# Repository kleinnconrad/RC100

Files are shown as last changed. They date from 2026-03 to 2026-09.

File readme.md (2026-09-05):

# 1:10 onroad RC car for speeds over 100 km/h

This project covers the system architecture and configuration of an 1:10 scale on-road touring car with the design goal of a consistently repeatable top speed of over 100 km/h without risking the car to be damaged or destroyed. The focus is on maximizing drive power while ensuring reliability and cost efficiency.

The technical challenge primarily results from the chosen scale and the limited tire diameter of 64 millimeters. While vehicles from 1:8 scale have physical advantages due to higher mass inertia, larger rolling circumferences, and a longer wheelbase, the 1:10 scale requires significantly higher rotor speeds. This leads to high mechanical stresses in the drivetrain. The low vehicle weight also requires precise aerodynamic and suspension tuning to ensure driving stability at high speeds.

The artefacts of this repository are:
* Architecture decision records (ADRs) in the `/architecture` directory
* System specification in the `specs/full_spec.yml` file
* Vehicle setup configurations in the `/setup_sheets` directory

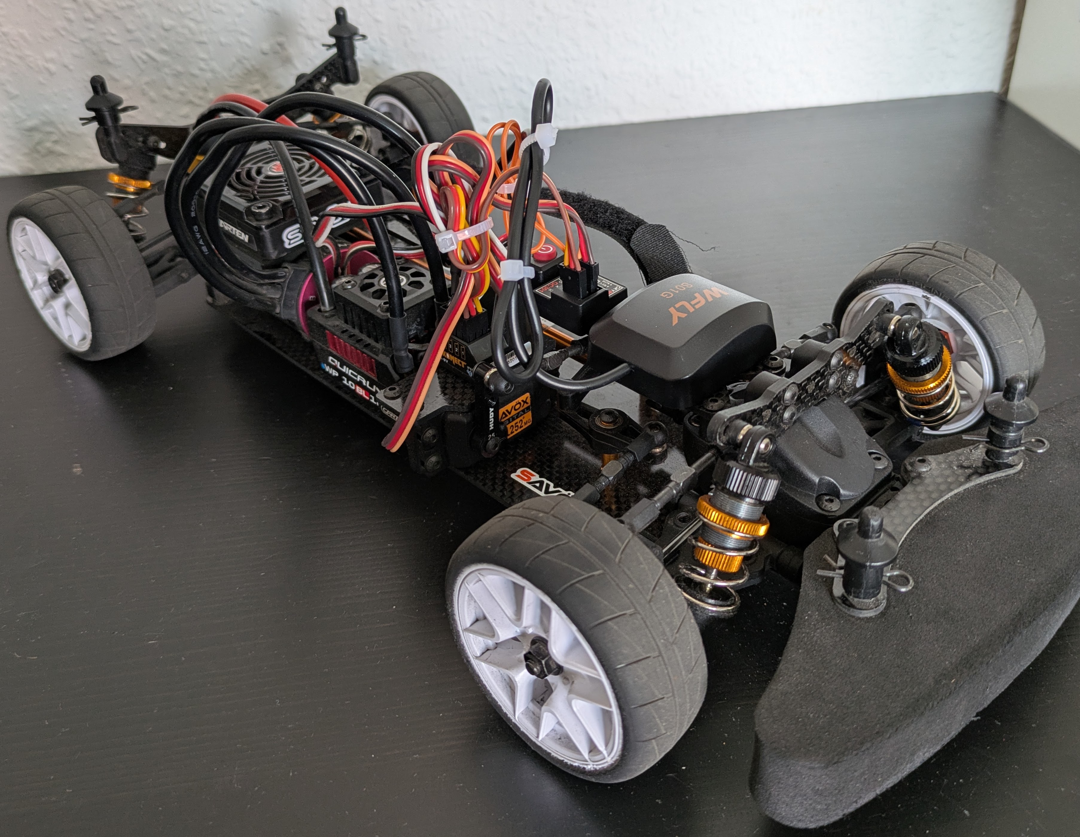
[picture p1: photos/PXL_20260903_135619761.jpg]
RC Car Photo 1
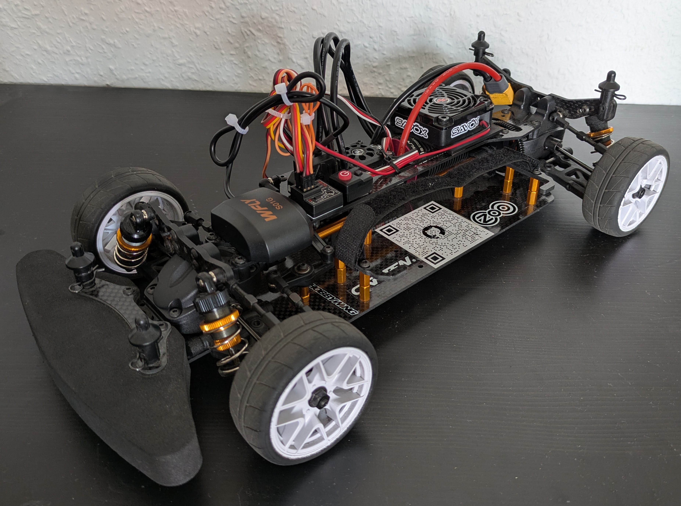
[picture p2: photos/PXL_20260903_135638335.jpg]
RC Car Photo 2
 

## Table of contents
* [Repository structure](#repository-structure)
* [Artefacts (ADR, specs, setup sheets)](#artefacts-adr-specs-setup-sheets)
* [Calculation models for drivetrain design](#calculation-models-for-drivetrain-design)
* [Learnings & modifications](#learnings--modifications)
* [Repository automation](#repository-automation)
* [Follow-up project: Telemetry system](#follow-up-project-telemetry-system)
* [Licensing](#licensing)

## Repository structure
* **`/architecture`**: Documentation of basic system designs
* **`/docs`**: Static web dashboard for visualizing the latest setup configurations
* **`/photos`**: Central directory for all image files
* **`/project`**: General project information
  * **`/costs`**: Cost tracking
  * **`/follow_up_projects`**: Documentation of related follow-up projects
* **`/scripts`**: Automation scripts
  * **`/calc`**: Calculation scripts
  * **`/plots`**: Generated plots
* **`/setup_sheets`**: Vehicle setup configurations
* **`/specs`**: Specifications of the vehicle components
  * **`/electronics`**: Selection and specification of electronic components such as motors, electronic speed controllers, and batteries
  * **`/mechanics`**: Chassis design, construction data, and specification of physical components
* **`/testing`**: Test results and performance measurement data
  * **`/error_list`**: Error logs and their resolutions
  * **`/tests`**: Logs and data of test drives

## Artefacts (ADR, specs, setup sheets)
The documentation of architecture decisions (ADRs), the specifications of all mechanical and electronic components, and the vehicle setup configurations are consistently maintained as structured YAML files (`.yml` or `.yaml`). The formal hierarchical structure of these artefacts is standardized as follows:

```mermaid
classDiagram
    class adr {
        +id: String
        +title: String
        +status: String
        +date: Date
        +context: Text
        +decision: String
        +rationale: Text
        +consequences: List
    }
    class adr_alternative {
        +option_id: Integer
        +name: String
        +type: String
        +evaluation: Text
    }
    adr *-- adr_alternative : considered_alternatives
    
    class spec {
        +properties: Object
        +integration_notes: Object
    }
    class spec_meta {
        +brand: String
        +model: String
        +type: String
    }
    spec *-- spec_meta : meta

    class setup {
    }
    class setup_meta {
        +date: Date
        +description: String
        +version: String
        +top_speed_kmh: Float
    }
    class setup_properties {
        +suspension_and_geometry: Object
        +drivetrain: Object
        +electronics_and_control: Object
    }
    setup *-- setup_meta : meta
    setup *-- setup_properties : properties
```

## Calculation models for drivetrain design
To avoid thermal or mechanical overload of the electronic components, custom-developed calculation models are used:
* **Gearing calculator (`scripts/calc/getriebe_calc.py`)**: Simulates the mechanical wheel load for the motor based on tire diameter and target speed, depending on available motor pinions. Setups are categorized into load zones for the defined drive system.
* **Limit calculator (`scripts/calc/max_speed.py`)**: Calculates the achievable top speed considering specific motor data, battery voltage, and defined thermal tolerance limits based on physical hardware specifications.

## Learnings & modifications (so far...)
This section documents the findings from previous tests & speedruns in 1:10 scale as well as the resulting modifications to the vehicle.

| Driving operation & environment |
|:---|
| **[L] Track selection**<br>A suitable track is crucial for success. Clean asphalt is absolutely necessary. The track should preferably not be bordered by walls or curbs. A minimum width of 8 meters is required. |
| **[L] Weather**<br>The weather is also important. Ensure there is no wind and conditions are dry. |
| **[L] Safety**<br>If the conditions are not right and you don't have a good feeling, no speedrun should be undertaken. |
| **[L] Driving practice**<br>You must learn to drive. It is necessary to familiarize yourself with the vehicle and the acceleration curve. It is important to steer the vehicle smoothly when it is far away. |

| Suspension & geometry |
|:---|
| **[M] Dampers & springs**<br>Very viscous shock oil was used and spring preload maximized. Stiff suspension is absolutely necessary to prevent loss of control due to diving. |
| **[M] Suspension geometry**<br>Rear toe-in of 2.5 degrees and 0 degrees camber. Front 0 degrees toe-in and 0 degrees camber. No experiments should be made here. |
| **[M] Sway bars**<br>The sway bars were removed. They are unnecessary for speedruns and pose a potential source of error. |
| **[M] Droop screws**<br>The droop screws were removed. Since the track is not manually cleaned, further lowering is not constructive. The screws are unnecessary for the regular 1:10 speedrun. |
| **[L] Weight distribution**<br>Care must be taken to ensure an even left/right weight distribution. Furthermore, the front must not be too light. |

| Drivetrain |
|:---|
| **[L] Motorization**<br>Sufficient motorization is less of a problem than often assumed. You shouldn't invest too much here. |
| **[M] Motor & gearing**<br>Use of a 3660 motor with a tall gear ratio instead of the usual 3650 motor. The motorization must be adapted to the available track. |
| **[M] Differential (front)**<br>A front spool was installed. During straight-line running at maximum speed, diff-out must be absolutely avoided; speed compensation is not desired. |
| **[L] Differential (rear)**<br>Making the rear differential stiffer is not necessary. The front spool is sufficient. |
| **[L] Thermal management**<br>Problems with ESC and motor temperature have not occurred yet. The problem is apparently overrated. |

| Electronics & control |
|:---|
| **[L] Control components**<br>**Do not skimp on the remote control and servo**. Lack of precision makes steering corrections a game of chance. You must invest in a remote control with hall sensors and a decent digital servo. |
| **[L] Assistance systems**<br>**Using a Gyro really makes a difference** and is highly recommended. |
| **[L] Steering mechanics**<br>The steering mechanism must move without resistance when disconnected from the servo. Mechanical resistance prevents the servo from returning precisely to the neutral position during slow steering inputs. In this state, the servo stops visibly but continues to draw current, indicated by audible noise, as it attempts to reach the neutral position. |
| **[L] `Steering Exponential Curve` (cubic polynomial)**<br>The steering exponential curve requires precise configuration. A setting of approximately -30 is recommended. |
| **[L] `Throttle Exponential Curve` (cubic polynomial)**<br>The throttle exponential curve requires precise configuration. A setting of approximately -40 is recommended. |

| Chassis & assembly |
|:---|
| **[L] Material selection**<br>Not all plastic parts should be replaced with aluminum. You must consider which parts are allowed to be destroyed in a crash. If easily replaceable plastic parts are replaced with aluminum, the impact energy finds more unfavorable paths. |
| **[L] Threadlocker**<br>Loctite on metal connections is absolutely mandatory. |
| **[L] Body**<br>The body should not be painted. A clear body allows a necessary view of the technology at all times. |
| **[L] Aerodynamics**<br>A wedge shape of the vehicle is necessary for efficient aerodynamics. To achieve this, the front body posts must be shortened as much as possible. |
| **[M] C-hub assembly**<br>The mounting screws of the C-hubs were loosened to eliminate mechanical resistance. Excessive tightening prevents the steering from moving freely, resulting in the previously described issue of an inaccurate servo neutral return. |
| **[M] Servo saver**<br>The servo saver was removed and an aluminum servo horn was mounted directly. This increases the risk of damage to the servo in the event of a crash. The servo saver was identified as a source of failure (steering oscillation) during speedruns. |

*(Legend: **[L]** = learning, **[M]** = modification)*

## Repository automation
Maintaining the specifications and architecture decisions formatted as YAML files triggers automated processes:
* **Aggregation of specifications**: Individual hardware specifications are merged into a central specification file in the root directory.
* **Cost overview**: Bill of materials and shopping lists are automatically derived from the specifications and updated.
* **Decision log**: Architecture decisions are automatically compiled into a chronological log.

## Follow-up project: Telemetry system
This project is followed by an independent project concerned with the development of a telemetry data system based on an ESP32 microcontroller. The goal is the sensory recording and transmission of driving dynamics parameters of the RC vehicle.



## Licensing
* The source code of the calculation models is subject to the MIT license.
* The hardware design, documentation, specifications, and test results are released under the Creative Commons attribution 4.0 international license. Own adaptations and commercial use are permitted, provided authorship is acknowledged.

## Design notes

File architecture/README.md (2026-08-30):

# Architecture Decision Records (ADRs)

This directory contains all fundamental architecture and hardware decisions for the RC100 project. **This file is generated automatically. Please do not edit manually.**

## Overview

| ID | Date | Title | Status | Decision |
| :--- | :--- | :--- | :--- | :--- |
| **ADR-001** | 2026-03-06 | Selection of the chassis platform and make-or-buy decision (100 km/h Benchmark) | 🟢 decided | MAKE - Carten T410R |
| **ADR-002** | 2026-03-06 | Selection of the brushless motor combo for 100 km/h speedruns | 🟢 decided | Hobbywing QuicRun WP10BL120 G2 Combo (3660SL 3700KV) |
| **ADR-003** | 2026-03-06 | Selection of the LiPo Battery for the 100 km/h Goal. | 🟢 decided | Absima GreenHorn Line V2 (3S / 5000mAh / 50C / Hardcase) |
| **ADR-004** | 2026-03-06 | Selection of the charger for 3S LiPo batteries | 🟢 decided | SkyRC S100neo |
| **ADR-005** | 2026-08-20 | Selection of the remote control system for 100 km/h speedruns | 🟢 decided | X9S Radio + Mini Waterproof 4-Channel Receiver RG4CHWP |
| **ADR-006** | 2026-08-21 | Selection of the steering servo for precise high-speed control | 🟢 decided | Savöx SC-1252MG+ |
| **ADR-007** | 2026-03-06 | Selection of active and passive motor cooling for 3S speedruns | 🟢 decided | Passive 36mm Alu Heat Sink combined with active 40x40mm High-Speed Alu Fan |
| **ADR-008** | 2026-02-25 | Selection of tires (belted rubber tires for asphalt) for 100 km/h speedruns | 🟢 Decided | Sweep HANKOOK Tread Belted tires Pre-glued set Pro-compound 36deg for Asphalt (SR-SSF-36AWPG) |
| **ADR-009** | 2026-03-12 | Selection of the aerodynamic body for 100 km/h speedruns | 🟢 decided | ZooRacing Hellcat (190 mm, 0.7mm thickness) |
| **ADR-010** | 2026-03-10 | Selection of the GPS measuring system to validate the 100 km/h mark | 🟢 decided | Ruddog GPS Performance Analyzer |
| **ADR-011** | 2026-08-30 | Selection of Gyro for vehicle stabilization | 🟢 Decided | SkyRC GC301 Gyro |

---

## Detailed Logs

### ADR-001: Selection of the chassis platform and make-or-buy decision (100 km/h Benchmark)
**Status:** decided | **Date:** 2026-03-06

#### Context
For the 100 km/h speedrun project, a mechanically stable basis is required. 
The platform must withstand 
extreme loads (approx. 44,000 rpm at the motor, massive 
centrifugal forces on the axles). 
The fundamental architecture question (Make or Buy) compares the construction of an own budget kit ("Make") 

with the purchase of an expensive, pre-assembled high-end competition chassis ("Buy"
). 
A critical risk for 3S use are differential gears made of plastic/composite, 
which often cannot withstand the torque.

#### Decision
> **MAKE - Carten T410R**

#### Rationale
The decision is made in favor of the "Make" option with the Carten T410R 
(~ 180 €). 
It is the only kit in the benchmark field of this price class that 
combines the essential requirements 
for a 3S/100 km/h run out of the box: 
1. A stiff 3mm carbon bottom plate (prevents dangerous fluttering). 
2. A robust shaft drive (eliminates the risk of skipping belts). 
3. Differential gears made of sintered metal (solves the knockout criterion of shearing 
plastic diffs). 
The massive price advantage over the Xray X4 '24 fully justifies 
the increased manual setup effort.

#### Consequences
- The metal differentials of the T410R must be shimmed precisely to guarantee zero play.
- The central aluminum driveshaft must be checked for concentricity before installation, as strong vibrations can occur with shaft setups.

---

### ADR-002: Selection of the brushless motor combo for 100 km/h speedruns
**Status:** decided | **Date:** 2026-03-06

#### Context
In order to accelerate a 1/10 touring car (Carten T410R) to 100 km/h, 
the gearing must be very 'tall' (high wheel load > 22 %). A 
classic 3650 motor (50 mm length) operates 
here at its thermal 
load limit. A drivetrain is absolutely required 
that delivers enough mechanical torque (motor size 3660) at 3S voltage 
(11.1V) and 
whose electronic speed controller (ESC) can safely handle the high stall currents during acceleration 
(min. 120A).

#### Decision
> **Hobbywing QuicRun WP10BL120 G2 Combo (3660SL 3700KV)**

#### Rationale
The decision is made in favor of the Hobbywing QuicRun G2 Combo. It eliminates 
the risk of failure of 
no-name motors and offers an optimally coordinated architecture (firmware of ESC 
and motor timing are optimally interlocked). 
The 3660 motor delivers the perfect 
rpm with its 3700KV on 3S 
(approx. 41,000 rpm) and has enough torque due to the longer rotor 
to confidently handle 
the calculated wheel load of approx. 24 %. This is the safest and 
most efficient solution on a budget under 100 €.

#### Consequences
- Packaging (Installation space): The 3660 motor is 10 mm longer than the standard size. The ESC and the receiver must be placed correspondingly further back in the T410R chassis.
- Pinion bore (IMPORTANT): Hobbywing usually delivers the 3660SL G2 with a 5.0 mm shaft (verify specifications with the dealer finally before ordering the pinion). A 48dp pinion with a 5 mm bore (e.g. Robinson Racing) is absolutely required.
- Power supply: The system voltage is strictly limited to 3S LiPo. A 4S operation would exceed the maximum permissible rotor speed of the motor.

---

### ADR-003: Selection of the LiPo Battery for the 100 km/h Goal.
**Status:** decided | **Date:** 2026-03-06

#### Context
In order to accelerate the RC100 project to over 100 km/h, the power source must be optimally 
matched to the 4000kV motor and the 120A ESC (Hobbywing QuicRun). 
A 2S LiPo (7.4V) would only deliver approx. 29,600 rpm, which is not sufficient for 100 km/h 
with a normal gear ratio. Therefore, a 3S LiPo (11.1V) is absolutely necessary to 
reach the calculated ~44,400 rpm. In addition, the battery must be able to briefly 
deliver extreme currents without dropping in voltage (voltage sag), and must be physically 
protected in the event of a crash at high speed.

#### Decision
> **Absima GreenHorn Line V2 (3S / 5000mAh / 50C / Hardcase)**

#### Rationale
The decision is made in favor of the Absima GreenHorn V2 3S LiPo. With a 50C 
discharge rate, it offers 
enough buffer for the massive current peaks when accelerating 
the 64T/38T gearing. 
The hardcase is a safety requirement for speedruns, as an impact at 100 km/h 
would immediately destroy and ignite a softcase LiPo. The pre-assembled XT60 connector 
guarantees a 
low contact resistance for the high currents.

#### Consequences
- Chassis modification: Since 3S hardcase batteries are approx. 35mm high, the upper carbon battery brace in the Carten T410R must be raised with 10mm spacers and longer M3 screws.
- Connector compatibility: The Hobbywing controller must absolutely be soldered with a matching XT60 connector (no Tamiya connectors at these currents!).
- Safety: Charging and storing the battery (55.5 Wh) may only be done under supervision in a Bat-Safe or a fireproof LiPo bag.

---

### ADR-004: Selection of the charger for 3S LiPo batteries
**Status:** decided | **Date:** 2026-03-06

#### Context
Charging the 3S LiPo battery defined in ADR-003 (11.1V, 5000mAh, 55.5 
Wh) requires a 
safe and powerful charger. To gently charge the battery 
with 1C (5 Amps), 
a charging power of at least 63 Watts 
(5 Amps * 12.6V end-of-charge voltage) is required. 
In addition, the charger must 
exactly monitor the cell voltages (balancing) and be able to measure the internal 
resistance of the cells to prevent fire hazards. The connector must 
be able to safely transmit the 
high currents via an XT60 plug.

#### Decision
> **SkyRC S100neo**

#### Rationale
The decision is made in favor of the SkyRC S100neo. It optimally covers the "sweet spot" 
between safety, 
performance and budget. The 100 Watts of internal power (AC) are more than sufficient 
to gently fully charge the 3S 5000mAh LiPo in about an 
hour. Particularly advantageous is 
the XT60 connector firmly integrated into the front panel, which makes dangerous and error-prone 
adapter cables 
superfluous. This fits perfectly with the architecture decision of the Absima battery.

#### Consequences
- Safety during charging: In addition to the XT60 main connector, the white JST-XH balancer cable of the battery must strictly be plugged into the port of the charger, otherwise the individual cells will not be monitored.
- Cable minimalism: No additional charging cables are required (battery is plugged directly into the device).
- Cooling: The charger has an active fan. During charging, ensure a safe stand and free air supply.

---

### ADR-005: Selection of the remote control system for 100 km/h speedruns
**Status:** decided | **Date:** 2026-08-20

#### Context
An RC car traveling at 100 km/h (approx. 27.7 meters per second) covers 
enormous distances in a few seconds. 
The remote control (transmitter) 
and the receiver 
must therefore absolutely have a stable radio connection 
and an absolutely reliable fail-safe 
so that the vehicle does not get out of control at the end 
of the acceleration stretch. 
A balance must be struck 
between maximum range incl. gyro support and a 
robust, 
failsafe MVP approach (Minimum Viable Product) that reduces the complexity in 
the setup.

#### Decision
> **X9S Radio + Mini Waterproof 4-Channel Receiver RG4CHWP**

#### Rationale
The tests with the Carson Reflex Wheel X1 showed insufficient steering precision, as the servo did not reproducibly return to the neutral position depending on the steering angle. To increase steering precision, the X9S Radio remote control was purchased in combination with the RG4CHWP receiver for 152 €.

#### Consequences
- Receiver installation: The RG4CHWP receiver is installed and the fail-safe must absolutely be programmed to brake/neutral.
- Interface compatibility: The operating voltage of the receiver must be matched with the BEC output voltage of the motor controller.
- Steering angle limitation: The steering deflections (Dual Rate) are adapted to the requirements of high-speed driving.

---

### ADR-006: Selection of the steering servo for precise high-speed control
**Status:** decided | **Date:** 2026-08-21

#### Context
At speeds of 100 km/h, enormous aerodynamic and mechanical 
forces act 
on the front wheels of the Carten T410R. A minimal jitter, play 
or a too slow 
reaction time of the steering servo can immediately lead to loss of control 
and total failure. 
In addition, space in a 1:10 touring car chassis 
is limited. Since our MVP remote control 
(Carson Reflex Wheel X1) does not have an electronic gyro, the servo must 
hold the 
straight line mechanically very precisely and powerfully. A servo 
with metal gears (robustness), 
high speed (~0.11s) and sufficient 
torque (approx. 9 kg) is required.

#### Decision
> **Savöx SC-1252MG+**

#### Rationale
Test drives showed that the previous setup did not provide the required steering precision. The servo did not reproducibly return to the neutral position. Therefore, a change was made to the Savöx SC-1252MG+ (52.72 €). It offers a speed of 0.07s and a torque of 7 kg. This ensures a precise return to the neutral position.

#### Consequences
- Servo horn: To minimize play in the steering system, a rigid aluminum lever (ALU CLAMP SERVO HORN - FUTABA, SAVÖX - 3-HOLE - 25T, item HUD293409) is mounted without a servo saver.
- BEC voltage: The BEC output voltage of the controller is configured to 6.0V.
- Dual-Rate: The maximum steering angle is limited on the remote control to ensure stability at 100 km/h.

---

### ADR-007: Selection of active and passive motor cooling for 3S speedruns
**Status:** decided | **Date:** 2026-03-06

#### Context
The targeted goal of 100 km/h requires the use of a 4000kV motor 
on a 
3S LiPo (11.1V), which leads to high speeds of approx. 44,400 rpm 
and an enormous 
tall gear load (64T/38T). Under these conditions, 
massive waste heat is generated in the motor 
within seconds. Without adequate 
cooling, there is a risk of 
demagnetization of the rotor (heat death) or melting 
of the insulation. 
Therefore, a strict thermal management system 
is absolutely necessary.

#### Decision
> **Passive 36mm Alu Heat Sink combined with active 40x40mm High-Speed Alu Fan**

#### Rationale
The decision is made in favor of a dual cooling system (active and passive). 
The 36mm 
aluminum clip-on heat sink fits perfectly on the Hobbywing 3652SL motor. 
The 40mm 
high-speed fan with aluminum frame offers the necessary hurricane 
due to speeds of up to 20,000 rpm 
to blow the heat away. An aluminum frame 
on the fan 
also prevents it from deforming under heat buildup, and 
serves as an additional 
mini heat sink.

#### Consequences
- Power supply: The fan must be plugged into a free slot on the DumboRC receiver (e.g. CH3 or CH4) to draw power from the ESC BEC.
- Cable management: Due to the high suction of the high-speed fan, all cables (especially antenna and servo cables) must absolutely be secured with cable ties so that they do not get caught in the rotor blades.
- Thermal paste: It is strongly recommended to apply a drop of PC thermal paste between the motor and the aluminum heat sink in order to minimize the thermal contact resistance.

---

### ADR-008: Selection of tires (belted rubber tires for asphalt) for 100 km/h speedruns
**Status:** Decided | **Date:** 2026-02-25

#### Context
At a target speed of 100 km/h and the associated high 
speeds 
of the wheels, standard rubber tires expand massively in the middle due to centrifugal force 
(the so-called "pizza cutter effect" or "ballooning"
). This leads to an immediate 
loss of control and often to the tire bursting. 
Pre-glued tires 
on rims with a 12mm hex hub 
(suitable for the Carten T410R chassis) are required, 
which retain their shape 100% under high centrifugal forces 
and whose rubber compound 
withstands the high friction heat on rough 
asphalt. 
In addition, the real track conditions (not 
dust-free normal asphalt vs. 
cleanly prepared race track) must be considered when choosing 
the tire tread (slick vs. grooved). 

#### Decision
> **Sweep HANKOOK Tread Belted tires Pre-glued set Pro-compound 36deg for Asphalt (SR-SSF-36AWPG)**

#### Rationale
The decision is made in favor of the pre-glued Sweep HANKOOK Tread 
Belted tires with 
the harder 36-shore asphalt compound. Although a treadless 
full slick physically 
offers the absolute top performance and maximum smoothness 
at 100 km/h, in real 
use on not optimally swept 
parking lots, it is too sensitive to fine dust (loss 
of traction). The 
Hankook tread can transport away light dirt and offers 
the safer and more good-natured driving behavior on normal asphalt. 
At the same time, 
the essential 
Kevlar fabric (belt) guarantees absolute safety against critical expansion.

#### Consequences
- Pre-check: Even factory pre-glued tires must absolutely be checked for manufacturing defects on the glue seam before the first run (pull briefly on the tire sidewall).
- Balancing: Since the smallest imbalances destabilize the chassis at 100 km/h, the wheels should ideally be balanced with an RC tire balancer and putty lead.
- Temperature window: The 36-shore compound is relatively hard. In order to build up maximum mechanical grip, the tires must be warmed up by 1-2 slow laps before the actual speedrun.

---

### ADR-009: Selection of the aerodynamic body for 100 km/h speedruns
**Status:** decided | **Date:** 2026-03-12

#### Context
At a target speed of 100 km/h (approx. 27.7 m/s), the body is 
no longer a purely visual component, but the primary aerodynamic protective layer. 
A classic, boxy body 
traps air under the front apron, 
which inevitably leads to a 'blow-over' (lifting off due to 
dynamic pressure). At the same time, 
the air resistance (drag coefficient) must not unnecessarily slow down the motor. 
The Carten T410R chassis requires a width of 190 mm. The material thickness is 
critical: 
Thin lexan (< 0.5 mm) deforms massively at 100 km/h.

#### Decision
> **ZooRacing Hellcat (190 mm, 0.7mm thickness)**

#### Rationale
The decision is made in favor of the ZooRacing Hellcat in the 0.7mm standard thickness. 
It represents the 
optimal compromise between minimum air resistance (for 
reaching 100 km/h) and safe 
downforce (prevention of blow-overs). Unlike very flat LMP bodies, 
it fits easily over 
the shock towers of the Carten T410R. The material thickness of 0.7mm 
guarantees 
that the body withstands the massive dynamic pressure at top speed and does not 
start to vibrate or rub against the tires.

#### Consequences
- Painting: The body is supplied unpainted. Special lexan paint (polycarbonate paint, e.g. Tamiya PS series) must be used, as normal paint would flake off.
- Assembly: The included rear wing must be screwed on very rigidly. The body holes must be precisely machined with lexan scissors and a body reamer.
- Chassis preparation: The foam bumper on the front of the Carten T410R must sit exactly flush with the inside of the front apron to prevent it from being pushed in at high speed.

---

### ADR-010: Selection of the GPS measuring system to validate the 100 km/h mark
**Status:** decided | **Date:** 2026-03-10

#### Context
The calculated mathematical models (axle speed, rolling resistance, 
voltage drop) 
must be validated in reality ('integration test' on the street) 
by hard telemetry data. 
Since the vehicle often only holds the top speed of 100 km/h for a time window 
of 2 to 3 seconds, a very high sampling rate (update frequency) of the 
measuring device is absolutely required. 
At the same time, the module must not 
negatively affect the vehicle weight (CG) 
and the aerodynamics.

#### Decision
> **Ruddog GPS Performance Analyzer**

#### Rationale
The decision is made in favor of the Ruddog GPS Performance Analyzer. It is 
the perfect 'fit-for-purpose' 
tool for this project. The 10Hz sampling rate 
guarantees that the exact top speed 
is recorded, even if 
it is only applied for a fraction of a second. The low weight 
of 38g does not change the driving behavior of the Carten T410R, and the Bluetooth app interface 
saves a heavy, readable display directly on the vehicle.

#### Consequences
- Signal constraint: The GPS signal easily passes through lexan bodies, but is massively blocked by carbon fibers. The module must not be mounted directly *under* the carbon upper deck in the Carten T410R. The optimal position is on the foam bumper in the front.
- Mounting: The device must be fixed very securely (e.g. with strong velcro or 3M Dual Lock) so that it does not fly away as a projectile in the event of a rollover at 100 km/h.

---

### ADR-011: Selection of Gyro for vehicle stabilization
**Status:** Decided | **Date:** 2026-08-30

#### Context
At high speeds of up to 100 km/h, the RC vehicle requires electronic stabilization to maintain a straight trajectory and prevent spin-outs. A gyro sensor detects unwanted rotational movements and automatically applies counter-steering via the steering servo. The selection of a gyro must balance reliability and cost. High-end gyros offer advanced features but exceed the current project budget.

#### Decision
> **SkyRC GC301 Gyro**

#### Rationale
The decision is made in favor of the SkyRC GC301 Gyro. The primary factor is cost. The Futaba and Power HD alternatives exceed the project budget. The SkyRC GC301 provides a cost-effective method to implement electronic stabilization for initial testing. If the performance of the GC301 proves insufficient during high-speed tests, a budget increase for a higher-tier gyro can be considered in a future iteration.

#### Consequences
- Installation: The gyro must be mounted aligned with the longitudinal axis of the chassis to function correctly.
- Calibration: The gyro gain must be adjusted. High gain causes steering oscillation, low gain provides insufficient stabilization.
- Testing: Initial low-speed tests are required to verify the correct direction of the counter-steering before attempting high-speed runs.

---

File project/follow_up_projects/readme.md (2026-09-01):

# Ideas for follow-up projects

**Sensors/telemetry** 
* Microcontroller/sensor solution for measuring ESC and motor temperature and the speed at the driveshaft. 

**IoT cloud data platform** 
* Setup of a real-time streaming pipeline (ESP32 via LTE) for GPS and ESC telemetry.
* Implementation of a cloud infrastructure for scalable storage and processing of vehicle data.
* Live dashboarding for real-time performance analysis during speedruns.

**Hardware scaling**
* Dual motor configuration for the Carten T410R chassis (CAD project).

**Data analytics (GPS and ESC telemetry)**
* Development of a regression model to estimate the real speed from ESC telemetry data.
* Structured evaluation of relevant experiments and speedrun test runs.
* Derivation of data-driven optimization approaches for maximum battery efficiency and absolute top speed.

**Assistance systems**
* Integration of hardware and software for assisted driving with the Carten T410R.

**Predictive maintenance**
* Development of a model for predicting thermal limits (motor/ESC) based on load profiles, RPM and ambient temperature.
* Long-term analysis of voltage sag under full load for data-driven evaluation of battery degradation (state of health).

**Computer vision & FPV systems**
* Integration of an FPV camera system with on-screen-display (OSD) for overlaying relevant live telemetry (speed, temperatures, battery level).
* Implementation of camera-based environment detection (e.g. via raspberry pi) to expand the assistance systems with lane detection and obstacle avoidance.

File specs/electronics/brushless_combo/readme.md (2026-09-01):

# Hobbywing QuicRun 120A ESC

## Table of contents
* [1. Throttle range calibration](#1-throttle-range-calibration)
  * [1.1 preparation of the transmitter](#11-preparation-of-the-transmitter)
  * [1.2 performing the calibration](#12-performing-the-calibration)
* [2. Parameterization of the "punch" (start mode) via LED program card](#2-parameterization-of-the-punch-start-mode-via-led-program-card)
  * [2.1 connecting the program card](#21-connecting-the-program-card)
  * [2.2 setting the parameter](#22-setting-the-parameter)
* [3. Ensure correct polarity of the motor](#3-ensure-correct-polarity-of-the-motor)
* [4. ESC programming](#4-esc-programming)

## 1. Throttle range calibration

### 1.1 preparation of the transmitter
* Set the throttle trim to the value 0 (neutral).
* Set end point adjustment (EPA) for throttle and brake to 100%.
* ABS braking functions must be disabled.
* Check throttle channel inversion (usually "REV" for futaba systems, "NOR" for other manufacturers).
* Turn on the transmitter.

### 1.2 performing the calibration
1. Connect the drive battery to the switched-off ESC.
2. Press and hold the SET button on the ESC.
3. Turn on the ESC using the main switch.
4. As soon as the red status LED starts flashing, release the SET button immediately.
5. **Neutral point:** Leave the throttle trigger in the neutral position. Press the SET button once. The green LED flashes once for confirmation.
6. **Full throttle endpoint:** Pull the throttle trigger to the maximum forward position (full throttle) and hold it at the mechanical stop. Press the SET button once. The green LED flashes twice.
7. **Full brake endpoint:** Push the throttle trigger to the maximum reverse position (full brake) and hold it at the mechanical stop. Press the SET button once. The green LED flashes three times.
8. Return the throttle trigger to the neutral position. The ESC completes the initialization process after approx. three seconds and is ready for operation.

---

## 2. Parameterization of the "punch" (start mode) via LED program card

### 2.1 connecting the program card
1. Make sure the ESC is turned off.
2. Plug the connection cable of the program card into the dedicated PRG port (3-pin) of the ESC.
3. Strictly observe polarity: The ground cable (black/brown) must be connected to the negative pole (-), the signal cable (white/orange) to the signal pole (S/P).
4. Connect the opposite end of the cable to the program card.

### 2.2 setting the parameter
1. Connect the drive battery and turn on the ESC. The numeric segment display of the program card is activated.
2. Iteratively press the **ITEM** button until the parameter for "start mode / punch" (usually menu item 4) is displayed on the left display field.
3. Press the **VALUE** button to specify the numeric value.
   * *Note for the present high-load gear ratio (43/72):* Value must absolutely be set to **1 (soft)** to minimize critical inrush currents (stall currents) and prevent triggering of the overcurrent protection circuit.
4. Press the **OK** button to write the changed value into the non-volatile memory of the ESC. (Motor usually gives an acoustic confirmation signal).
5. Turn off the ESC and disconnect the physical connection to the program card.

## 3. Ensure correct polarity of the motor
The fit of the motor in the Carten requires an inverse polarity compared to the standard so that technical and physical direction of movement are congruent. The technical directions of rotation are controlled differently, so that purely inverting on the remote control is not sufficient.

## 4. ESC programming

| Item | programmable items | option 1 | option 2 | option 3 | option 4 | option 5 | option 6 | option 7 | option 8 | option 9 |
| :--- | :--- | :--- | :--- | :--- | :--- | :--- | :--- | :--- | :--- | :--- |
| 1 | running mode | forward with brake | **(forward / reverse with brake)** | forward with reverse | | | | | | |
| 2 | cutoff voltage | disabled | 2.6V/cell | 2.8V/cell | **(3.0V/cell)** | 3.2V/cell | 3.4V/cell | | | |
| 3 | punch | **(level 1)** | level 2 | level 3 | level 4 | level 5 | level 6 | level 7 | level 8 | level 9 |
| 4 | drag brake force | **(0%)** | 5% | 10% | 20% | 40% | 60% | 80% | 100% | |
| 5 | max. Brake force* | **(25%)** | 50% | 75% | 100% | disabled | | | | |
| 6 | max. Reverse force | **(25%)** | 50% | 75% | 100% | | | | | |
| 7 | neutral range | 6% | **(9%)** | 12% | | | | | | |
| 8 | timing | 0° | 3.75° | 7.5° | **(11.25°)** | 15° | 18.75° | 22.5° | 26.25° | |
| 9 | LiPo cells* | **(auto)** | 2S | 3S | 4S | 5S | 6S | | | |
| 10 | BEC voltage | **(6.0V)** | 7.4V | | | | | | | |

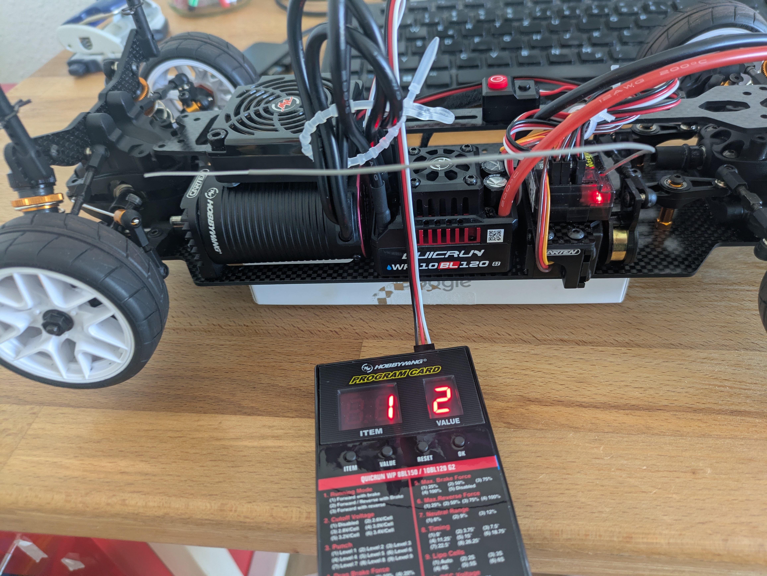
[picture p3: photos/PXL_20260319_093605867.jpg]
Program card ESC


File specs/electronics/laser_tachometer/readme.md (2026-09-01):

# Laser tachometer test

## Table of contents
* [Validation & findings](#validation--findings)
* [Theoretical speed](#theoretical-speed)

**Component:** Digital laser tachometer (optical speed measurement)
**Date:** 2026-03-16
**Status:** Verified / ready for use

## Validation & findings

* **Measurement method:** The laser tachometer was tested in RPM mode (revolutions per minute) for validation.
* **Reference test run:** To verify the accuracy of the measurement, the test was performed on a known, already existing RC car. To capture the optical laser signal, a reflection strip was applied to the outer flank of the wheel.
* **Plausibility check:** The recorded RPM value and the resulting speed are plausible. The measuring device provides data and is thus approved for data acquisition on the Carten T410R speedrun project.

## Theoretical speed

v = (d * π * rpm * 60) / 1000²

**Test calculation with the recorded values:**
* Wheel diameter (d): 64 mm
* Measured RPM (rpm): 2340.2

v = (64 * 3.14159 * 2340.2 * 60) / 1,000,000
**v ≈ 28.23 km/h**

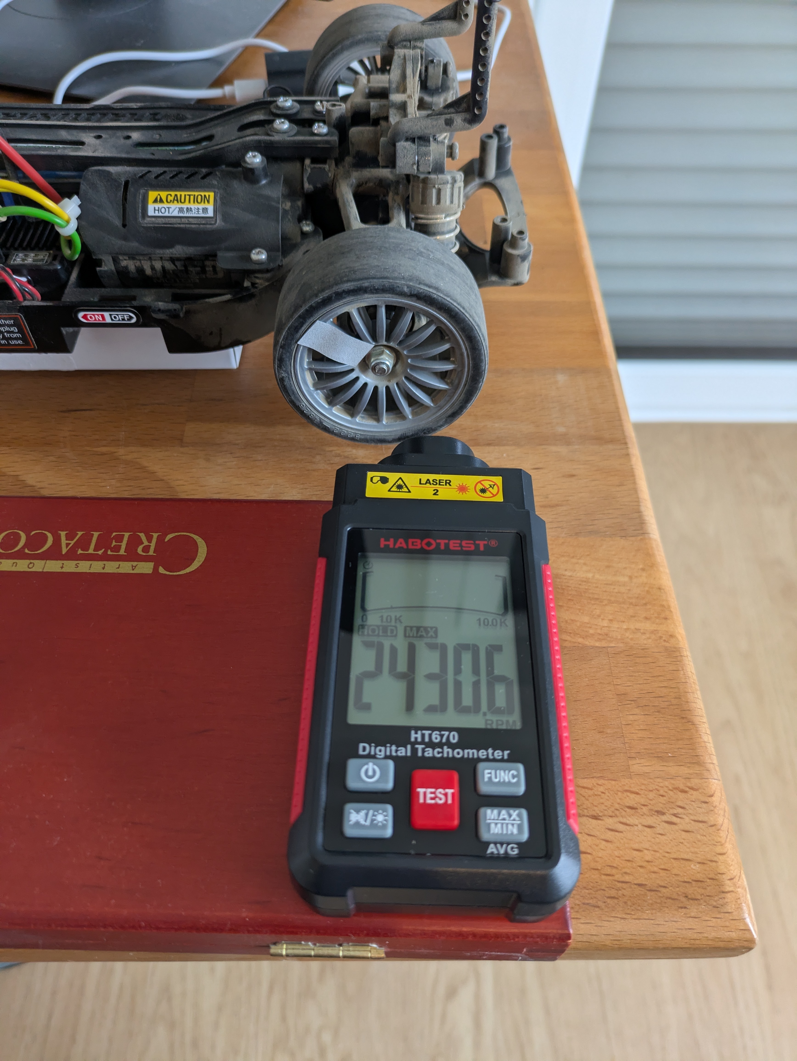
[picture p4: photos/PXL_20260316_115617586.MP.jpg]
laser tachometer test setup


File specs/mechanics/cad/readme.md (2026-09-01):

# 3D printed parts

## Table of contents
* [Included files](#included-files)
  * [1. Motor fan mount (`fan_mount.stl`)](#1-motor-fan-mount-fan_mountstl)
  * [2. LiPo battery dummy (`lipo_mock.stl`)](#2-lipo-battery-dummy-lipo_mockstl)
  * [3. RC car maintenance stand (`stojan_3dprint_25.stl`)](#3-rc-car-maintenance-stand-stojan_3dprint_25stl)
* [Sources](#sources)

This folder contains 3D printed parts (STL files) for the RC car **Carten T410R** as well as a maintenance stand.

## Included files

### 1. Motor fan mount (`fan_mount.stl`)
* **Author:** [@kleinnconrad](https://github.com/kleinnconrad) (own design)
* **Description:** A fan mount for a **50x50 mm motor fan from hobbywing**. Designed for mounting in the Carten T410R for installation and cooling of the motor.

### 2. LiPo battery dummy (`lipo_mock.stl`)
* **Author:** [@kleinnconrad](https://github.com/kleinnconrad) (own design)
* **Description:** A placeholder object in the size of a **3S hardcase LiPo battery**. This model is used for planning installations, electronics and cable management in the Carten T410R. It replaces the physical battery during the design phase.

### 3. RC car maintenance stand (`stojan_3dprint_25.stl`)
* **Author:** [@Upgrade25](https://www.printables.com/@Upgrade25)
* **Description:** A maintenance stand for RC cars (scale 1:10). Intended for repairs, setup work or as a rest.

---

## Sources

The RC maintenance stand (`stojan_3dprint_25.stl`) is not mine. The original files and all credits go to the original designer on printables:

* **Original model:** [RC car maintenance stand 1:10 on printables](https://www.printables.com/model/1200600-rc-car-maintenance-stand-110/files)
* **Designer profile:** [Upgrade25](https://www.printables.com/@Upgrade25)

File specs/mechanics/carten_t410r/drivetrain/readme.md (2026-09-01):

## Drivetrain dashboard: Speed targets & thermal zones

## Table of contents
* [Drivetrain dashboard: Speed targets & thermal zones](#drivetrain-dashboard-speed-targets--thermal-zones)
  * [Reading guide for the dashboard:](#reading-guide-for-the-dashboard)
* [The "wheel load %" formula](#the-wheel-load--formula)
  * [The calculation](#the-calculation)
  * [The load zones (for 3650 motors / 4000kV on 3S)](#the-load-zones-for-3650-motors--4000kv-on-3s)

The following dashboard visualizes the physical limits of the **Carten T410R** in combination with the specified **3660 brushless motor (3700KV on 3S)**. 

It shows the direct correlation between the chosen pinion size, the resulting mechanical load (wheel load in %) and the achievable axle speed.

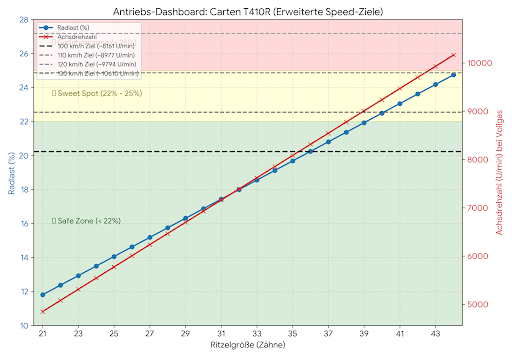
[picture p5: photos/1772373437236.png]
Drivetrain dashboard with speed targets


### Reading guide for the dashboard:
* **The dashed lines (grayscale):** Mark the required axle speed for our milestones (100, 110, 120 and 130 km/h) with a tire diameter of 65 mm.
* **The red curve (axle speed):** Shows the theoretically applied speed of the wheels at full throttle per pinion. Where this curve intersects one of the dashed lines, the respective speed target is reached.
* **The blue curve (wheel load):** Shows the mechanical load of the motor. 
* **The colored zones (background):** Define the thermal tolerance limits of the 3660 motor.
  * 🟢 **safe zone (< 22 %):** Continuous load possible without problems.
  * 🟡 **sweet spot (22 % - 25 %):** optimal for speedruns, keep an eye on thermal limit.
  *  **Danger zone (> 25 %):** Acute risk of overheating, only for extreme short sprints.

**Conclusion of the visualization:** The primary project goal of **100 km/h** is achieved from a **35T/36T pinion**. The wheel load is at this point still absolutely safe in the deep green zone. The setup offers mechanical reserves up to approx. 125 km/h.

## The "wheel load %" formula

The **wheel load in percent** calculated in our scripts is an empirical indicator for the mechanical load on the motor. It is based on the reciprocal of the final drive ratio (FDR). 

The smaller the FDR (i.e. the "taller" the gear ratio), the less leverage the motor has. It must consequently apply more raw power to push the car against the exponentially increasing air resistance.

### The calculation
1. **Calculate final drive ratio (FDR):**
   FDR = (spur gear / motor pinion) * internal ratio
   *(On the Carten T410R, the internal ratio is 2.47)*

2. **Calculate wheel load factor:**
   Wheel load (%) = (1 / FDR) * 100

**Example:** With a 72T spur gear and a 36T pinion, the FDR is `(72 / 36) * 2.47 = 4.94`.
The wheel load is thus `(1 / 4.94) * 100 = 20.2 %`.

### The load zones (for 3650 motors / 4000kV on 3S)
These zones have established themselves in practice as guide values for temperature and current monitoring:

* **< 19.0 % (green zone):** High leverage. optimal for twisty tracks, stop-and-go and long bashing. Electronics stay cool.
* **19.0 % - 22.0 % (yellow sweet spot):** Ideal balance for speedruns. The car reaches top speed, electronics get very warm, needs cooling down after 1-2 runs.
* **22.0 % - 25.0 % (red danger zone):** Extreme load. Exclusively suitable for short, linear acceleration races with active fan cooling.
* **> 25.0 % (heat death):** The leverage is no longer sufficient. The motor draws stalling currents, converts energy almost entirely into heat and risks the immediate destruction of ESC or rotor.

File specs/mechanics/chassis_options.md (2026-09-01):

### Scale 1:10 kit benchmark (100 km/h focus)

| Property / specification | Carten T410R (base) | tamiya TT-02 SRX | xpress arrow AT1S | xpress execute XQ2S | SNRC R23 / R3G | rlaarlo AK917 | xray X4 '24 (benchmark) |
| :--- | :--- | :--- | :--- | :--- | :--- | :--- | :--- |
| **Drive concept** | shaft | shaft | shaft | 2-belt | 2-belt | shaft | 2-belt |
| **Chassis bottom plate** | 3mm **carbon** | plastic tub | FRP (fiberglass) | FRP (fiberglass) | **carbon** | **carbon** or aluminum | premium **carbon** |
| **Differential gears** | **metal** (sintered metal) | front spool / rear bevel diff | plastic / composite | plastic / composite | plastic / composite | **metal** (1:8 components) | plastic (competition grade) |
| **Suspension system** | C-hubs | C-hubs (TRF) | C-hubs | C-hubs | C-hubs | C-hubs | pivot-ball / active-toe |
| **Motor position** | rear right | rear right | rear right | mid-motor | mid-motor | mid | mid (ultra-low) |
| **Torsional stiffness (flex)**| very stiff | soft (tub flex) | medium (FRP flexes more) | medium (FRP flexes more) | very stiff | very stiff | optimally calculated |
| **Risk at 3S / 100 km/h**| low (shaft highly robust) | high (instability due to flex) | medium (FRP flutter possible) | high (belt skipping) | medium (belt risk) | very low (1:8 drivetrain) | very low (perfect mechanics) |
| **Approx. Price (kit/roller only)** | **~ 180 €** | **~ 250 €** | **~ 150 €** | **~ 150 €** | **~ 140 €** | **~ 170 €** | **~ 750 €** |

Note: Differential gears made of plastic / composite represent a mechanical risk in the high-speed range.

### Scale 1:8 / 1:7 speedrun benchmark

Note: The project focuses on the 1:10 scale. The listing of the 1:8 and 1:7 scales serves solely for completeness.

| Property / specification | arrma limitless V2 (1:7) | hobao hyper VTE2 (1:7) |
| :--- | :--- | :--- |
| **Drive concept** | shaft with spool | shaft |
| **Chassis bottom plate** | 3mm **aluminum** | 3mm **aluminum** |
| **Differential gears** | **metal** (mod 1.0) | **metal** (mod 1.0) |
| **Suspension system** | pivot-ball | pivot-ball |
| **Motor position** | mid | mid |
| **Torsional stiffness (flex)**| very stiff | very stiff |
| **Risk at > 150 km/h** | very low (designed for speedruns) | very low (designed for speedruns) |
| **Approx. Price (kit/roller only)** | **~ 350 €** | **~ 400 €** |

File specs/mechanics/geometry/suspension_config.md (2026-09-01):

## Chassis geometry: Toe & camber (the 100 km/h setup)

## Table of contents
* [Chassis geometry: Toe & camber (the 100 km/h setup)](#chassis-geometry-toe--camber-the-100-kmh-setup)
  * [1. Toe](#1-toe)
  * [2. Camber](#2-camber)
  * [Setup plan (Carten T410R)](#setup-plan-carten-t410r)
  * [Adjustment on the chassis](#adjustment-on-the-chassis)

The chassis geometry decides at high speeds whether the car drives stable straight ahead or breaks out uncontrollably. Here are the most important physical parameters and our specific speedrun setup.

### 1. Toe
The toe describes the angle of the wheels in relation to the longitudinal axis of the car, **when looking down from above**.

* **Toe-in:** The wheels point slightly **inwards** at the front (`/ \`).
  * *Effect:* The car stubbornly wants to drive straight ahead and stabilizes itself. It turns into corners more sluggishly.
* **Toe-out:** The wheels point slightly **outwards** at the front (`\ /`).
  * *Effect:* The car turns very aggressively into corners, but becomes highly nervous on the straight and begins to "wander".

### 2. Camber
The camber describes the angle of the wheels, **when looking at the car from the front or rear**.

* **Negative camber:** The wheels tilt inwards towards the chassis center at the top (`/ \`).
  * *Effect:* When rolling in a corner, the outer wheel presses flat onto the asphalt and generates maximum grip.
* **Positive camber:** The wheels tilt outwards at the top (`\ /`).
  * *Effect:* Drives unstable and has no use in on-road RC applications.
* **Neutral camber (0°):** The wheel is exactly vertical (`| |`).
  * *Effect:* Maximum contact patch on the straight (as long as the tire does not deform due to centrifugal force).

---

### Setup plan (Carten T410R)

For an uncompromising speedrun (exactly straight ahead, maximum stability), the following basic setup applies:

| Axle / parameter | setting | physical reason for 100 km/h |
| :--- | :--- | :--- |
| **Front axle: Toe** | **0° (neutral)** | minimization of rolling resistance when driving straight ahead. |
| **Rear axle: Toe** | **2.5° toe-in** | increase in driving stability. Prevents the rear axle from breaking out at high speeds. (Predefined on the Carten T410R by the rear toe blocks). |
| **Camber (front & rear)**| **0° (neutral)** | maximum contact patch of the tire when driving straight ahead for optimal traction. |

### Adjustment on the chassis
On the Carten T410R, the geometry is adjusted via the **turnbuckles** (metal rods with right/left-hand threads):
* **Toe (front):** Changing the length of the rods of the *steering linkage*.
* **Camber:** Changing the length of the *upper wishbones*.

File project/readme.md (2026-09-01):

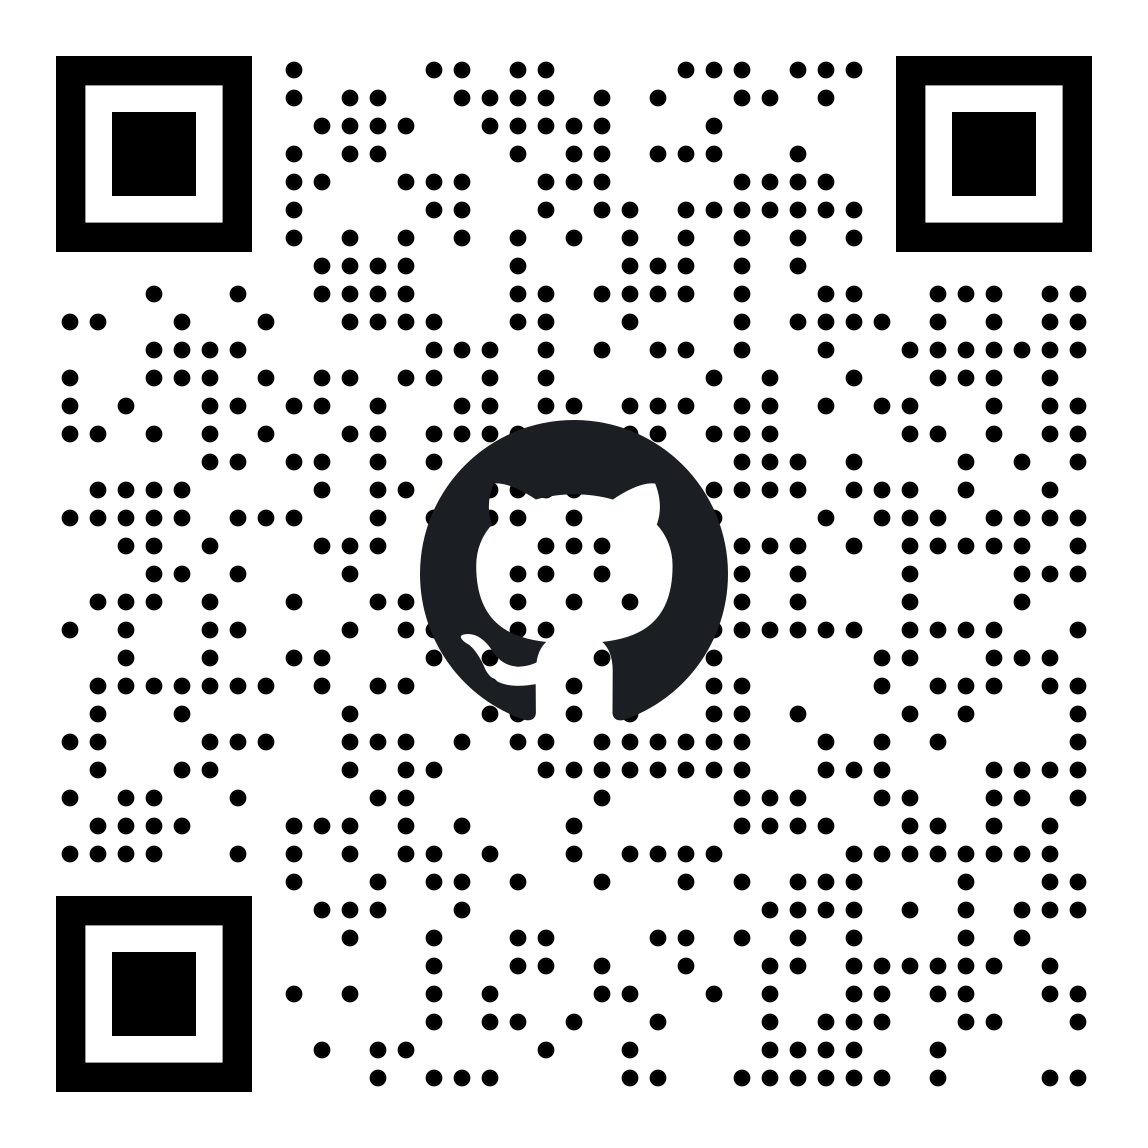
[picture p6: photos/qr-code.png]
qr


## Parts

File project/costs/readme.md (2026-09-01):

# Bill of materials (BOM) - Carten T410R speedrun project

## Table of contents
* [Hardware](#hardware)
* [Cost breakdown](#cost-breakdown)

**Date:** 2026-08-20

## Hardware

| Pos | category | article description | article no. | Dealer | quantity | price |
|:---:|:---|:---|:---|:---|:---:|---:|
| 1 | **chassis** | CARTEN T410R - 1:10 4WD touring car kit | 75-NHA102 | RC-KleinKram | 1 | 179,99 € |
| 2 | **control** | carson REFLEX wheel X1 - 2.4GHz incl. 4-channel receiver (old) | 17-500148 | RC-KleinKram | 1 | 34,99 € |
| 3 | **drive** | hobbywing combo WP10BL120G2 with 3660SL-3700KV-G2 | HW38030211 | monster hopups | 1 | 82,78 € |
| 4 | **energy** | absima greenhorn vol.2 LiPo 3S 11.1V-50C 5000 HC (XT60) | AB-4140014 | monster hopups | 1 | 32,36 € |
| 5 | **mechanics** | robinson-racing motor pinion hardened steel 5mm 48DP 43 teeth | RR-2043 | monster hopups | 1 | 9,18 € |
| 6 | **cooling** | hobbywing fan with cooling fins for 36mm motor (60mm) | HW86080120 | monster hopups | 1 | 9,99 € |
| 7 | **charging tech** | SkyRC S100 neo LiPo 1-6s 10A 100W AC | SK100202-01 | monster hopups | 1 | 44,95 € |
| 8 | **steering** | amewi 4409MG AMX digital servo low-profile (old) | AW-28995 | tamico shop | 1 | 23,99 € |
| 9 | **testing** | QWORK digital tachometer | - | amazon | 1 | 13,88 € |
| 10 | **body** | ZooRacing ZR-0006-07 - HellCat - 1:10 touring car | 10-ZR-0006-07 | RC-KleinKram | 1 | 30,99 € |
| 11 | **tool** | tamiya 86015 - PS-15 metallic red (100ml) | 17-86015 | RC-KleinKram | 1 | 8,99 € |
| 12 | **tool** | tamiya 86012 - PS-12 silver (100ml) | 17-86012 | RC-KleinKram | 1 | 8,99 € |
| 13 | **tool** | tamiya 86005 - PS-5 black (100ml) | 17-86005 | RC-KleinKram | 1 | 8,99 € |
| 14 | **tool** | bittydesign BDSS-37855-C curved scissors | 18-BDSS-37855-C | RC-KleinKram | 1 | 10,99 € |
| 15 | **wheels & tires** | sweep HANKOOK tread belted tires pre-glued 36deg | SR-SSF-36AWPG | LMI-racing | 1 | 29,99 € |
| 16 | **telemetry** | ruddog GPS/GNSS speed & performance analyzer | RP-0525 | RCFOX | 1 | 54,85 € |
| 17 | **ESC programming** | hobbywing programming box LED universal | HW30501003 | modellbau metz | 1 | 11,49 € |
| 18 | **control** | X9S radio + RG4CHWP receiver | KN-X9S-4CH | RCFOX | 1 | 152,00 € |
| 19 | **steering** | Savöx SC-1252MG+ low-profile servo | SA_SC-1252MG+ | RCFOX | 1 | 52,72 € |
| 20 | **steering** | ALU CLAMP SERVO HORN 25T (HUD293409) | HUD293409 | RCFOX | 1 | 21,50 € |
| 21 | **spare parts** | CARTEN T410R - 1:10 4WD touring car kit | 75-NHA102 | RC-KleinKram | 1 | 179,99 € |
| 22 | **mechanics** | CARTEN NBA360 steel spur gear 48DP 68 teeth | 75-NBA360 | - | 1 | 15,99 € |
| 23 | **telemetry** | WFLY S01G GPS-modul | - | - | 1 | 18,00 € |
| 24 | **steering** | SkyRC GC301 Gyro | - | - | 1 | 25,00 € |

---

## Cost breakdown

| Description | amount |
|:---|---:|
| **Pure vehicle costs:** | **660,49 €** |
| Costs for tools, infrastructure & spare parts (pos. 2, 7, 8, 9, 11-14, 16, 17, 21): | 402,10 € |
| **Total costs:** | **1062,59 €** |

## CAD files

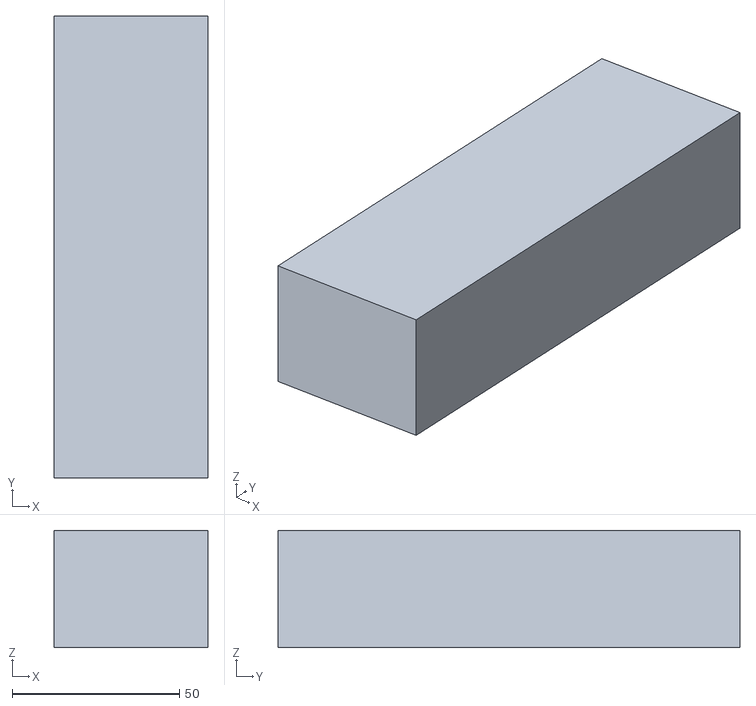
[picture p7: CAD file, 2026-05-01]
specs/mechanics/cad/lipo_mock.stl
46.0 x 138.0 x 35.0

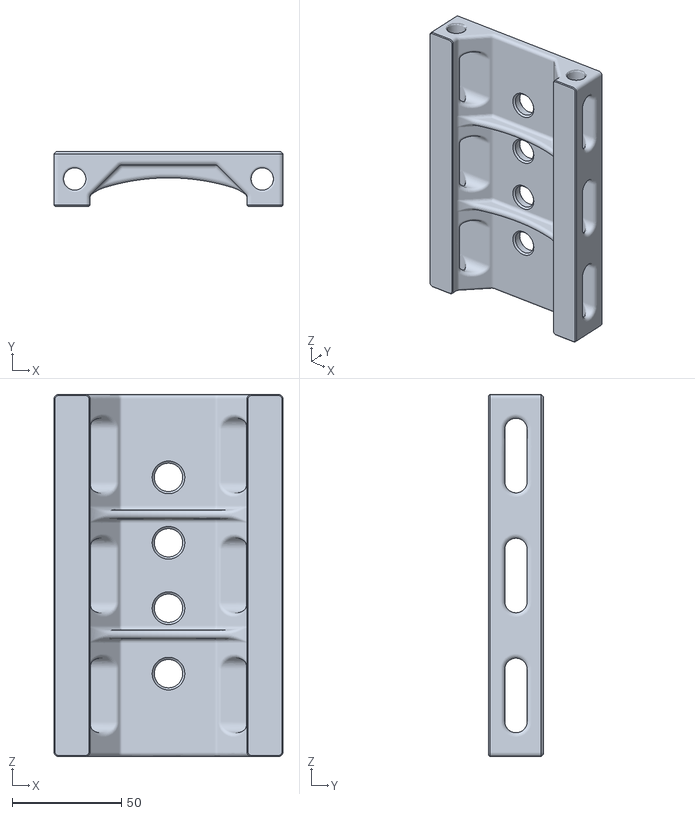
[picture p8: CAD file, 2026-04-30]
specs/mechanics/cad/stojan_3dprint_25.stl
105.0 x 25.0 x 166.0

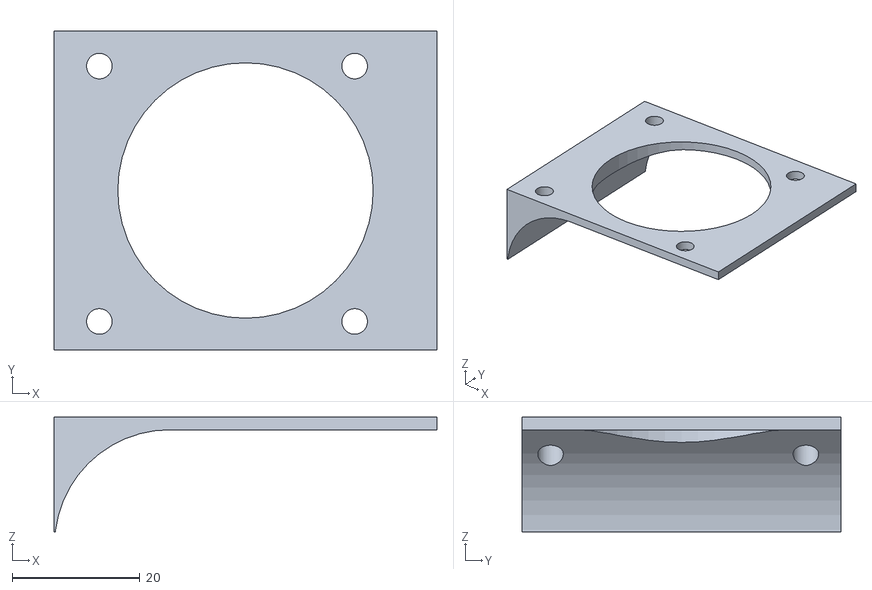
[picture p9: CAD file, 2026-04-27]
specs/mechanics/cad/fan_mount.stl
60.0 x 50.0 x 18.0

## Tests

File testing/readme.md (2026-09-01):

# Metrics

## Table of contents
* [Weight](#weight)
* [Weight distribution](#weight-distribution)
* [Dimensions](#dimensions)
* [Performance](#performance)

## Weight

| Component | weight |
| :--- | :--- |
| Vehicle with electronics (without battery) | 1.254 g |
| Battery | 391 g |
| Body | 75 g |
| GPS | 37 g |
| **Total** | **1.757 g** |

## Weight distribution
*without gps and body and with spool in front instead of differential
**Optimal weight distribution must be tested**

| | grams | ratio | | grams | ratio |
| :--- | :--- | :--- | :--- | :--- | :--- |
| **left** | 790 | 49% | **front** | 727 | 45% |
| **right** | 834 | 51% | **rear** | 893 | 55% |
| **total** | 1624 | 100% | **total** | 1620 | 100% |

## Dimensions 

| Dimension | value |
| :--- | :--- |
| Length (without body) | 362 mm |
| Width (without body) | 185 mm |
| Height (to highest point rear shock tower) | 75 mm |

## Performance
| Specification | value |
| :--- | :--- |
| Max. axle speed | 11,200 rpm |
| Max. motor speed | 46,256 rpm |
| Max. driveshaft speed | 27,625 rpm |
| Internal gear ratio | 2.47 |
| Total gear ratio | 4.13 |
| Battery | 3S (11.1V / 12.6V fully charged) |

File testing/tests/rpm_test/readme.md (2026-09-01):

# Test log - idle speed

## Table of contents
* [Test setup](#test-setup)
* [Theoretical top speed](#theoretical-top-speed)
* [Damage incurred](#damage-incurred)

**Date:** 2026-03-17.  
**Status:** completed (with damage to driveshaft and cup joints)

## Test setup

* **Measurement method:** Optical speed detection (RPM) using a laser tachometer.
* **Test environment:** Unloaded test (vehicle jacked up, drivetrain runs without ground contact/load resistance).
* **Execution:** A reflection strip was taped to the outer flank of the right rear wheel for clean signal generation. The measurement was taken at 100% throttle position via the carson remote control.
* **Result:** The system ran stably and without dropouts. Nevertheless, damage occurred. A maximum wheel speed of **11,200 RPM** was recorded.

## Theoretical top speed

v = (d * π * rpm * 60) / 1,000,000

v = (64 * 3.14159 * 11200 * 60) / 1,000,000
**v ≈ 135.11 km/h**

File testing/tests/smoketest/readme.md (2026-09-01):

# Smoke test

## Table of contents
* [Current setup](#current-setup)
* [Test report & problem description](#test-report--problem-description)
* [Solution & next steps](#solution--next-steps)

## Current setup
* **Motor:** 3660 brushless
* **Specification:** 3700 KV
* **Pinion:** 43 teeth (43T)
* **ESC punch level:** 5 (default)

## Test report & problem description
During the initial smoke test, it became apparent that the **punch (start behavior/acceleration aggressiveness) was set too hard**. 
Due to the combination of the 3660 / 3700 KV motorization and the 43T gear ratio, the vehicle is difficult to start with the standard punch level of 5.

## Solution & next steps
* **Measure:** Order a hobbywing programming card.
* **Goal:** Significantly reduce the punch value via the ESC to ensure a smoother starting behavior and better control.

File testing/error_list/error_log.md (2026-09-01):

# Error log and resolutions

| No. | Date | error | resolution |
| :--- | :--- | :--- | :--- |
| 1 | smoketest / 2026-03-17 | **ESC punch too aggressive:** The factory punch level (level 5) proved to be too hard for the long gear ratio. This made starting difficult and led to ESC emergency shutdowns during the 1st test drive. | Procurement of a programming card. The punch value was reduced to level 1. In addition, the vehicle is pushed slightly when starting. |
| 2 | 2026-03-17 | **total loss of gearbox:** The motor pinion slipped forward due to an insufficiently fixed grub screw. The asymmetrical engagement destroyed the plastic main gear and deformed the pinion bore. | Installation of a new 48DP motor pinion made of hardened steel (5 mm bore) and a kimbrough 72T upgrade main gear. The pinion was secured with medium-strength threadlocker (Loctite). |
| 3 | 2026-03-17 | **loss of locking pins:** Due to the high speeds (> 25,000 RPM) in the speed test, the O-rings of the cup joints slipped. As a result, the locking pins were thrown out. | For the future, a more flexible and stable fixation of the locking pins is being evaluated to withstand the rotational forces. |
| 4 | 2026-03-17 | **wrong motor polarity:** The set technical forward gear on the remote control corresponded to the physical reverse gear. | The motor polarity was reversed and the mechanical endpoints of the ESC were retaught to the remote control. |
| 5 | 2026-03-26 | **loosening of the wheel suspension:** The screw connection of the ball joint on the rear left wheel suspension loosened completely during the 3rd test drive. | All ball joint screw connections on the wishbones were dismantled and secured with liquid threadlocker (Loctite). Metal screws were tightened. |
| 6 | 01.04. - 16.04.2026 | **spongy front end behavior / dancing rear:** At increasing speeds, the front axle showed a lack of guidance. The unlocked differential and the rear weight favored instability. | Iterative optimization: 1. Additional weight on the front bumper (up to 175 g). 2. Installation of horseshoe springs for a harder servo saver. 3. Symmetrical chassis geometry: Camber set to -1.5°, toe-in to 1.5° and steeper wishbone angles. |
| 7 | 2026-04-03 | **rear-end collision:** During the 7th test drive, an accident occurred in which the rear right wheel suspension was mechanically damaged. | Disassembly of the chassis and complete replacement of the defective components on the rear right wheel suspension. |
| 8 | 2026-04-16 | **collision with driver:** A loss of control during a speedrun (9th test drive) resulted in an impact against the driver's foot. | Determination to conduct future high-speed tests exclusively on significantly larger and obstacle-free asphalt areas. |
| 9 | 2026-04-19 | **displacement of the bevel gear:** After the 1st speedrun session, the bevel gear of the front driveshaft mount had migrated by approx. 2 mm on the shaft (presumably breakage of the locking pin). | The bevel gear was pushed back completely onto the shaft with a positive fit, screwed tight and the screw connection secured with superglue. |
| 10 | 2026-04-19 | **driveshaft in resonance:** Due to the high speeds, the driveshaft started vibrating (whipping) and caused contact on the servo mount (already observed in the speed test). | No mechanical interventions were made, as the shaft remained undamaged and the contact was classified as uncritical. |
| 11 | 2026-04-19 | **pushed out ball bearing:** A ball bearing on the front differential housing was pushed half out of its seat by the occurring loads. | The condition was initially rated as technically uncritical, as no blockage or consequential damage occurred. |
| 12 | 2026-07-19 | **instability during strong acceleration:** Incorrect chassis tuning limited the speed. Causes: Completely blocked anti-roll bars, asymmetrical wheel camber in front and asymmetrical toe-in in rear. | The anti-roll bars were completely removed. The chassis geometry on the front and rear axles was set exactly symmetrically. |
| 13 | 2026-07-26 | **destabilization by wind influence:** Upcoming wind led to the destabilization of the vehicle and resulted in a crash. The battery compartment was damaged. A remaining residual restlessness also prevented the full utilization of the vehicle's performance. | Test runs will be carried out exclusively in calm conditions in the future. A spool is installed. |
| 14 | 2026-08-22 | **inaccurate steering neutral return:** Excessive tightening of the C-hub mounting screws created mechanical resistance. This prevented the steering mechanism from moving freely, causing the servo to fail to return precisely to the neutral position. | The mounting screws of the C-hubs were loosened to eliminate the mechanical resistance. |

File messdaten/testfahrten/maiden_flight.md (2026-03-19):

# Testbericht - Erste unstrukturierte Testfahrt

**Datum:** 17.03.2026  
**Status:** Gescheitert (Testabbruch)

## Schadensbericht

* **Kritischer Montagefehler (Antriebsstrang):** Die Madenschraube des Motorritzels war unzureichend fixiert (bzw. nicht korrekt auf der flachen Stelle der Motorwelle positioniert). Durch die hohen Fliehkräfte und Vibrationen ist das Hartstahl-Ritzel auf der Welle nach vorne gerutscht.
* **Totalschaden Getriebe:** Das Verrutschen führte zu einem asymmetrischen Eingriff der Zahnräder. Das Hauptzahnrad (Spur Gear) aus Kunststoff wurde dadurch komplett abrasiert/zerstört. Gleichzeitig hat sich die Bohrung des Motorritzels durch die extreme Hebelwirkung und das Durchdrehen auf der Welle irreparabel verformt.

* **Punch zu hoch eingestellt für die lange Übersetzung:**
Der Motor konnte bei der Übersetzung von 43 zu 72 Zähnen und einem Punch von 5 nicht oder kaum andrehen. **Zwingend erforderlich ist es den Punch auf 1 einzustellen und das Fahrzeug etwas anzuschieben**. Bei der Testfahrt ist der ESC beim anfahren öfter in die Notabschaltung gegangen.

* **Motor falsch gepolt:**
Die gewählte Polung (technischer Vorwärtsgang) entsprach nicht dem physikalischen Vorwärtsgang. Unter der Vermutung die Drehrichtungen seien kommutativ, wurde bei der Testfahrt die Throttle Einstellung an der Fernsteuerung auf "REV" gesetzt. Dadurch wurde das Auto im technischen Rückwärtsgang nach vorne gefahren. Dies erklärt neben dem Punch und der langen Übersetzung das schwierige anfahren.

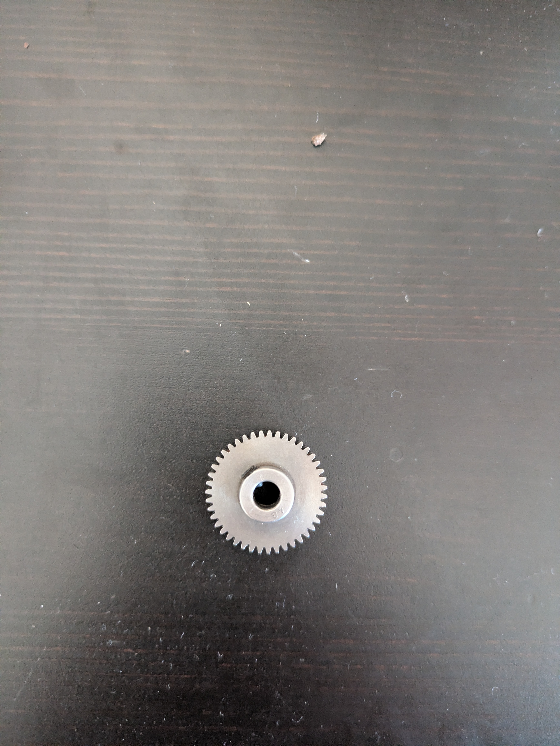
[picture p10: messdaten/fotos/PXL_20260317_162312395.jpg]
Schadensbild Antriebsstrang 1

*Abbildung 1: Zustand des Antriebsstrangs nach dem Testabbruch.*

Schadensbild Antriebsstrang 2
*Abbildung 2: Detailaufnahme der Schäden an Hauptzahnrad und Ritzel.*

## Korrekturen
1. Beschaffung eines neuen 48DP Motorritzels aus gehärtetem Stahl (5mm Bohrung).
2. Beschaffung eines Upgrade-Hauptzahnrads (z.B. Kimbrough 72T 48DP) kompatibel mit dem Carten T410R Mitnehmer.
3. Sichere Montage des neuen Ritzels mit mittelfester Schraubensicherung (Loctite).
4. Neukalibrierung des Hobbywing ESC an die Carson-Fernsteuerung (mechanische Endpunkte anlernen). 
5. Punch unbedingt auf 1 setzen.
6. Fahrzeug beim anfahren leicht anschieben, um Notabschaltungen des ESC zu verhindern.
7. Motor umpolen.

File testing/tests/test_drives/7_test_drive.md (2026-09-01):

# Test log: 7. Test drive

## Table of contents
* [Metadata](#metadata)
* [Goal of the test drive](#goal-of-the-test-drive)
* [Test course and result](#test-course-and-result)
* [Error pattern and problems encountered](#error-pattern-and-problems-encountered)
* [Planned measures](#planned-measures)
* [Implemented adjustments](#implemented-adjustments)

## Metadata
* **Date:** 2026-04-03
* **Location:** Parking lot (40 m length)
* **Focus:** Front end stability
* **Status:** (with accident-related abort)

## Goal of the test drive
Checking the driving stability on the front axle after implementing two targeted modifications: The attachment of 175g additional weight to the front bumper for further shift of center of gravity as well as the installation of an additional horseshoe spring on the servo horn for a harder setting of the servo saver. 

## Test course and result
The measures were a success. The vehicle lay stable and the steering was significantly more precise due to the harder servo saver. **On the relatively short test track of just under 40 meters, 55 km/h could be reached effortlessly and in a controlled manner.**

## Error pattern and problems encountered
Unfortunately, a rear-end collision occurred during the test drive. The vehicle suffered a mechanical defect: The rear right wheel suspension was damaged, which led to an immediate abort of the test drive.

## Planned measures
The high-speed setup on the front axle has proven itself and remains in place for now. The next steps focus on repairing:

* **Repair rear axle:** Disassembly, damage analysis and replacement of the defective parts of the rear right wheel suspension.
* **Track selection:** For the next test, a significantly longer track must be found in order to safely drive and brake the vehicle.
* **Additional horseshoe spring on the servo horn:** The third horseshoe spring will be pulled onto the servo horn to set the servo saver as hard as possible.

**Conclusion for the next rollout:**
The setup problem on the front axle is considered solved. The vehicle now offers the necessary mechanical basis and stability. The targeted 100 km/h seem possible with this tuning. Before the tests can be continued, the complete repair of the rear axle has top priority.

## Implemented adjustments
No special findings.

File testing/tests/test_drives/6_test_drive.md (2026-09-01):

# Test log: 6. Test drive

## Table of contents
* [Metadata](#metadata)
* [Goal of the test drive](#goal-of-the-test-drive)
* [Test course and result](#test-course-and-result)
* [Error pattern and problems encountered](#error-pattern-and-problems-encountered)
* [Planned measures](#planned-measures)
* [Implemented adjustments](#implemented-adjustments)

## Metadata
* **Date:** 2026-04-02
* **Location:** Underground garage
* **Focus:** Shift of center of gravity & stabilization of the front end
* **Status:** Partial 

## Goal of the test drive
Elimination of the spongy driving behavior at the front end (front axle) by a targeted change of the center of gravity to the front. For this purpose, 150 grams of additional weight were glued directly onto the front bumper to generate more pressure on the front wheels and improve steering precision.

## Test course and result
The modification showed the hoped-for basic effect. The driving behavior of the car has become noticeably more stable due to the additional weight. The weight shift to the front is the right approach, but the overall handling is still not satisfactory.

## Error pattern and problems encountered
Although an improvement has occurred, the front end still lacks the necessary precision and guidance. The sponginess is reduced, but not completely eliminated. The current setup is not yet sufficient to keep the vehicle precisely and calmly on course.

## Planned measures
In order to finally get the driving behavior at the front end under control and make the car exactly controllable, the following steps will be followed in the next setup:

* **Increase front weight:** An even higher weight will be applied to the front bumper and tested to force the center of gravity further forward and maximize downforce.
* **Evaluation of a spool (solid axle):** The installation of a spool (completely locked differential) on the front axle will be checked. This should prevent the front wheels from pulling unevenly, thus drastically improving straight-line stability and stability under load.

**Conclusion for the next rollout:**
The shift of the center of gravity to the front was a partial success and counteracted the spongy front end. For the next tests, it must now be iteratively checked whether a further increase in weight is sufficient or whether a mechanical intervention in the form of a spool brings the final solution for direct and controllable handling.

## Implemented adjustments
No special findings.

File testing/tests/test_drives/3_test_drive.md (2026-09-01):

# Test log: 3. Test drive

## Table of contents
* [Metadata](#metadata)
* [Goal of the test drive](#goal-of-the-test-drive)
* [Test course and result](#test-course-and-result)
* [Error pattern and problems encountered](#error-pattern-and-problems-encountered)
* [Planned measures](#planned-measures)
* [Implemented adjustments](#implemented-adjustments)

## Metadata
* **Date:** 2026-03-26
* **Location:** Underground garage
* **Focus:** Steering & chassis mechanics
* **Status:** Failed

## Goal of the test drive
Checking and evaluating the steering behavior after a recent realignment of the servo saver.

## Test course and result
The primary test goal (evaluation of the servo saver) could not be fully completed due to a mechanical failure.

## Error pattern and problems encountered
During the test drive, the screw connection of the ball joint on the **rear left wheel suspension** loosened. This led to an immediate loss of driving stability and made an immediate abort of the test inevitable in order to avoid consequential damage to the chassis or drivetrain.

## Planned measures
In order to permanently solve the problem and take preventive action on the other wheel suspensions, the following steps were carried out after the abort:

* **Securing the ball joints:** The screw connections of all four ball joints of the wheel suspensions were dismantled, checked and then secured against vibrating loose again with liquid threadlocker (Loctite). *(Note: The contact of Loctite with the plastic ball cups was monitored/cleaned).*
* **Safety check of the screw connections:** All remaining screws of the vehicle that engage in metal threads (are not screwed into plastic components) were checked for correct and tight fit and tightened where necessary.

**Conclusion for the next rollout:**
The mechanical integrity of the wheel suspension should now be restored. The original test of the servo saver must be repeated during the next drive.

## Implemented adjustments
No special findings.

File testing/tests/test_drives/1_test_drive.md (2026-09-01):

# Test log: 1. Test drive

## Table of contents
* [Metadata](#metadata)
* [Goal of the test drive](#goal-of-the-test-drive)
* [Test course and result](#test-course-and-result)
* [Error pattern and problems encountered](#error-pattern-and-problems-encountered)
* [Planned measures](#planned-measures)
* [Implemented adjustments](#implemented-adjustments)

## Metadata
* **Date:** 2026-03-17
* **Focus:** Exploration
* **Status:** Failed (test aborted).

## Goal of the test drive
No special findings.

## Test course and result
No special findings.

## Error pattern and problems encountered
* **Critical assembly error (drivetrain):** The grub screw of the motor pinion was insufficiently fixed (or not correctly positioned on the flat spot of the motor shaft). Due to the high centrifugal forces and vibrations, the hard steel pinion slipped forward on the shaft.
* **Total loss of gearbox:** The slipping led to an asymmetrical engagement of the gears. The main gear (spur gear) made of plastic was completely shaved off/destroyed as a result. At the same time, the bore of the motor pinion deformed irreparably due to the extreme leverage and spinning on the shaft.

* **Punch set too high for the tall gear ratio:**
The motor could not or hardly start with the gear ratio of 43 to 72 teeth and a punch of 5. **It is absolutely necessary to set the punch to 1 and slightly push the vehicle to start**. During the test drive, the ESC often went into emergency shutdown when starting.

* **Motor polarity reversed:**
The chosen polarity (technical forward gear) did not correspond to the physical forward gear. Assuming the rotation directions were commutative, the throttle setting on the remote control was set to "REV" during the test drive. This caused the car to drive forward in the technical reverse gear. This explains the difficult starting in addition to the punch and the tall gear ratio.

## Planned measures
1. Procurement of a new 48DP motor pinion made of hardened steel (5mm bore).
2. Procurement of an upgrade main gear (e.g. Kimbrough 72T 48DP) compatible with the Carten T410R hub.
3. Secure mounting of the new pinion with medium strength threadlocker (Loctite).
4. Recalibration of the hobbywing ESC to the carson remote control (teach mechanical endpoints).
5. Absolutely set punch to 1.
6. Push the vehicle slightly when starting to prevent emergency shutdowns of the ESC.
7. Reverse motor polarity.

## Implemented adjustments
No special findings.

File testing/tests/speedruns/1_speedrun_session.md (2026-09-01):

# 1. Speedrun test report

## Table of contents
* [Summary of test runs](#summary-of-test-runs)
* [Post-run inspection and damage report](#post-run-inspection-and-damage-report)
* [Conclusion](#conclusion)

**Date:** April 19, 2026  
**Location:** Bauhaus parking lot  
**Available track length:** approx. 130 meters

## Summary of test runs
The speedrun session comprised a total of 7 consecutive attempts on the test track mentioned above. The goal was to explore the top speed under the given space conditions (130 meters for acceleration and braking distance).

* **Number of attempts:** 7
* **Measured top speed:** **103 km/h** (reached in the 7th and final attempt)

*Note: Breaking the 100 km/h mark over such a strictly limited distance proves an excellent and very aggressive power delivery of the drive.*

## Post-run inspection and damage report
After the runs were completed, the chassis was subjected to a detailed visual and mechanical inspection. Severe structural failures did not occur, which speaks for the basic stability of the model. However, two load-specific abnormalities were documented:

1. **Driveshaft (whipping / resonance):**
   Due to the very high speeds, the central driveshaft started to vibrate (whip). As a result, there was slight mechanical contact with the servo mount.

2. **Front differential housing (ball bearing):**
   A ball bearing on the front differential housing was pushed half out of its seat by the occurring forces.
   * *Assessment:* Technically uncritical at the moment, since the system did not block and there was no consequential damage to the gears. **It is suspected that the cup joint shifted approx. 2 mm along the longitudinal axis towards the driveshaft.** Suspected cause is the breakage of the locking pin as a result of fixation with superglue. The occurring vibrations at this point require a more flexible attachment of the locking pin.
   * **Final diagnosis on 2026-04-20:** The bevel gear of the front driveshaft mount is actually pushed a few millimeters positively onto the shaft. The screw connection loosened slightly and the bevel gear migrated by approx. 2 mm. The bevel gear was now dismantled. Then the bevel gear was completely pushed onto the shaft and tightly screwed. Superglue was used to secure the screw connection.
   
## Conclusion
With a measured top speed of 103 km/h, the test series was a complete success. The chassis has largely withstood the high loads. The defects found are typical side effects in the high-speed range (rotational forces and vibrations) and can be eliminated through targeted, small optimizations to the drivetrain.

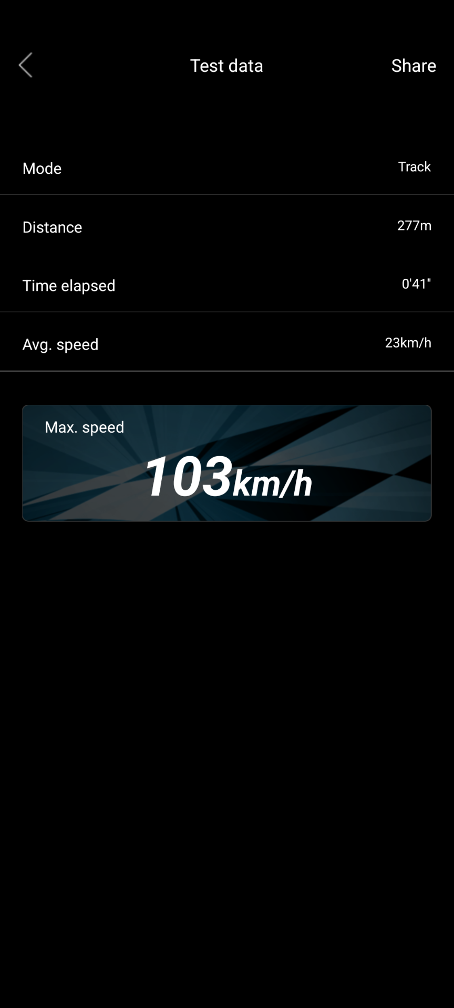
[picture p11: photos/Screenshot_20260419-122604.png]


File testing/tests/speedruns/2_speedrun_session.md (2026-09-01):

# 2. Speedrun test report

## Table of contents
* [Summary of test runs](#summary-of-test-runs)
* [Post-run inspection and error analysis](#post-run-inspection-and-error-analysis)
* [Conclusion](#conclusion)

**Date:** July 19, 2026  
**Location:** Bauhaus parking lot  
**Result:** unsuccessful

## Summary of test runs
* **Measured top speed:** **72 km/h**

The vehicle showed unstable driving behavior at higher speeds and during strong acceleration. This significantly limited the maximum achievable speed.

## Post-run inspection and error analysis
A subsequent inspection of the vehicle revealed three major configuration errors on the chassis that were responsible for the instability:

1. **Incorrect installation of the anti-roll bars:**
   The mounting screws of the anti-roll bars were fully tightened. This led to a rigid fixation on the chassis and blocked the function of the anti-roll bars.

2. **Camber asymmetry (front axle):**
   An asymmetrical setting of the wheel camber was found on the front axle.

3. **Toe asymmetry (rear axle):**
   An asymmetrical setting of the toe-in was identified on the rear axle.

**Corrective measures:**
All three identified configuration errors were corrected. The anti-roll bars are completely removed, as they are superfluous for speedruns, and the chassis geometry on the front and rear axles was set symmetrically.

## Conclusion
The instability of the vehicle during strong acceleration and speeds up to 72 km/h was presumably due to an incorrect chassis setup. By removing the anti-roll bars, correcting the wheel camber, and correcting the toe-in, the mechanical prerequisites for more stable driving behavior in future tests were created.

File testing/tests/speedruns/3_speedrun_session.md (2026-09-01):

# 3. Speedrun test report

## Table of contents
* [Basic data](#basic-data)
* [Test results](#test-results)
* [Incident and damage analysis](#incident-and-damage-analysis)
* [Measures](#measures)

## Basic data
* **Date:** July 26, 2026
* **Location:** Bauhaus parking lot
* **Result:** unsuccessful

## Test results
* **Measured speed:** 75 km/h
* **Driving behavior in calm conditions:** Smoothness has improved compared to previous tests. This confirms the effectiveness of the modifications.
* **Driving stability:** A residual restlessness is still present. The full utilization of the maximum vehicle performance is therefore excluded.

## Incident and damage analysis
* **Wind influence:** The onset of wind led to the destabilization of the vehicle.
* **Incident:** The instability led to a crash.
* **Damage:** The battery compartment was damaged.
* **Consequence:** The test was aborted.

## Measures
* Execution of test runs exclusively in calm conditions.
* Installation of a spool.

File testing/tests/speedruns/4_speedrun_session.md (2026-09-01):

# 4. Speedrun test report

## Table of contents
* [Basic data](#basic-data)
* [Test results](#test-results)
* [Incident and damage analysis](#incident-and-damage-analysis)
* [Measures](#measures)

## Basic data
* **Date:** August 2, 2026
* **Location:** Bauhaus parking lot
* **Result:** unsuccessful

## Test results
* **Measured speed:** 77 km/h
* **Driving stability:** A final attempt with a front differential. Driving stability is lost as soon as steering corrections are made during the run.

## Incident and damage analysis
* **Incident:** At approx. 80 - 90 km/h crash into a euro pallet
* **Damage:** Rear differential box, three wishbone mounts, battery mount, motor mount, main gear, bottom plate strongly affected.
* **Consequence:** The test was aborted.

## Measures
* A second Carten kit was ordered as a spare parts depot. The vehicle will be rebuilt and configured.
* Definitive installation of a spool.
* Check weight distribution (especially left/right)

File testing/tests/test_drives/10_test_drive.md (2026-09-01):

# Test log: 10. Test drive

## Table of contents
* [Metadata](#metadata)
* [Goal of the test drive](#goal-of-the-test-drive)
* [Test course and result](#test-course-and-result)
* [Error pattern and problems encountered](#error-pattern-and-problems-encountered)
* [Planned measures](#planned-measures)
* [Implemented adjustments](#implemented-adjustments)

## Metadata
* **Date:** 2026-04-16
* **Location:** Underground garage
* **Focus:** Front end stability and symmetry check (readjustment of chassis)
* **Status:** Successful optimization / residual restlessness present

## Goal of the test drive
Checking the chassis optimizations made on the front axle. The focus was on the question of whether the adjustment of the camber angle and the wishbone angles as well as the setting of a toe-in of approx. 1.5° eliminate the spongy front end behavior. The test was deliberately carried out without the additional weight on the front bumper in order to isolate the purely mechanical stability of the chassis.

## Test course and result
The front end behavior has noticeably improved as a result of the symmetry measures. The vehicle reacts more precisely and the aggressive nervousness of previous drives is reduced. Nevertheless, the front end still shows a slight restlessness during load changes and increasing speed.

## Error pattern and problems encountered
* **Residual restlessness front end:** Despite optimized geometry, the front axle is not yet absolutely planted. The weight distribution is identified as the cause; the heavy battery and motor shift the center of gravity (COG) so much that the front axle generates too little downforce without additional weight.
* **Dancing rear:** During this test drive, a slight dancing of the rear axle was observed. 
* **Drivetrain:** The unlocked differential has a negative effect on directional stability under load both at the front and at the rear, since the power distribution between the wheels fluctuates with minimal grip differences.

## Planned measures
* **Weight management:** Reattachment of the additional weight to the front bumper to balance the center of gravity and calm the front axle.
* **Drivetrain optimization:** Examination of the installation of a spool (solid axle) on the front axle or a stronger locking of the differentials to minimize the dancing of the rear and the restlessness in the front end.
* **Fine tuning:** Checking the symmetry under load conditions with mounted additional weight.

## Implemented adjustments
* **Toe-in:** Set to approx. 1.5° on both sides at the front to stabilize straight-line stability.
* **Camber angle:** Adjusted front left and right to approx. 1.5° (negative).
* **Wishbone angle:** The angles of the front wishbones were set symmetrically steeper to ensure a more even compression behavior.

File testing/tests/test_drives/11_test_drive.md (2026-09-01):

# Test log: 11. Test drive

## Table of contents
* [Metadata](#metadata)
* [Goal of the test drive](#goal-of-the-test-drive)
* [Test course and result](#test-course-and-result)
* [Planned measures](#planned-measures)
* [Implemented adjustments](#implemented-adjustments)

## Metadata
* **Date:** 2026-07-22
* **Location:** Underground garage
* **Focus:** Stability of straight-line driving
* **Status:** Residual restlessness present

## Goal of the test drive
Checking driving stability and straight-line driving after modification of the chassis. Specifically, it was investigated whether the correction of the camber setting and the removal of the anti-roll bars lead to a more stable straight-line drive.

## Test course and result
Despite the chassis adjustments, restlessness in straight-line driving was still observed during the drive. The modifications made did not lead to the targeted directional stability.

## Planned measures
* **Toe setting:** The toe on the front axle will be set to 0 degrees in the next step.

## Implemented adjustments
* **Camber setting:** Correction of the camber angle.
* **Anti-roll bars:** Removal of the anti-roll bars on the axle.

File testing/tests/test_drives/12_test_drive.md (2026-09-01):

# Report 12. Test drive

## Table of contents
- [Basic data and setup](#basic-data-and-setup)
- [Results](#results)
- [Measures](#measures)

## Basic data and setup
- **Date:** 2026-08-09
- **Location:** Bauhaus
- **Goal:** Checking the straight-line driving behavior during strong acceleration.
- **Background:** Rebuilding the vehicle after a total loss in the 4th speedrun session.
- **Setup changes compared to previous version:**
  - Installation of a front spool.
  - Mounting of 150 g additional weight on the front bumper (added during the test).

## Results
- The optimized chassis geometry did not lead to an improvement in driving behavior at high speeds.
- The installation of the front spool did not improve driving behavior.
- The mounting of the additional weight on the front bumper does not improve driving behavior.
- The vehicle breaks out to the left during strong acceleration. The cause is very likely torque twist due to the high-torque motorization.

## Measures
- Replacement of the motor from a high-torque to a high-speed design (priority 1). QuicRun 3652SL G2 sensorless motor 5400kV 3.175mm shaft
- Increase in spring stiffness.
- Checking the tires.
- Checking servo and servo saver or steering precision
- Installation of "perfect pass" https://github.com/ambrmart/arduino-rc-launch-control
- Installation of a gyro

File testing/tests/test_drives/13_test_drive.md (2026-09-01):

# Report 13. Test drive

## Table of contents
- [Basic data and setup](#basic-data-and-setup)
- [Results](#results)
- [Measures](#measures)

## Basic data and setup
- **Date:** 2026-08-23
- **Location:** Bauhaus parking lot
- **Goal:** Evaluation of driving behavior following modifications to the suspension and steering components.
- **Background:** The shock absorbers were filled with #1000 shock oil and spring preload was increased. A konect X9S remote control and a Savöx servo were installed to increase steering precision. The steering exponential curve was set to linear. The C-hub screws were loosened to minimize mechanical resistance and ensure an accurate return of the servo to the neutral position.

## Results
- The vehicle exhibits increased stability.
- Corrective steering maneuvers during the run can be executed effectively.
- The vehicle does not maintain constant contact with the road surface. This is attributed to a potentially faulty geometry setup and surface irregularities on the test track. These irregularities exceed the physical capabilities of the light 1:10 scale Carten T410R chassis.
- The driving skills of the pilot are insufficient.

## Measures
- Driving practice must be intensified.
- A test track with smoother asphalt and without curbs or other obstacles must be identified.
- The suspension geometry and weight distribution must be analyzed and adjusted.

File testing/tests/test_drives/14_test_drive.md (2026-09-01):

# Report 14. Test drive

## Table of contents
- [Basic data and setup](#basic-data-and-setup)
- [Results](#results)
- [Measures](#measures)

## Basic data and setup
- **Date:** 2026-09-01
- **Location:** Underground car park
- **Goal:** Evaluation of driving behavior with a Gyro
- **Background:** Gyro was installed and gain was set to 40

## Results
- The vehicle exhibits increased stability.
- Torque steer is nearly completely gone.
- The vehicle maintains a straight line while accelerating and when suddenly releasing the acceleration trigger.
- Corrective steering by the Gyro is clearly visible during the runs.

## Measures
- Checking the Gyro calibration at different speeds on a speedrun track

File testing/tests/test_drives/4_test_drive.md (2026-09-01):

# Test log: 4. Test drive

## Table of contents
* [Metadata](#metadata)
* [Goal of the test drive](#goal-of-the-test-drive)
* [Test course and result](#test-course-and-result)
* [Error pattern and problems encountered](#error-pattern-and-problems-encountered)
* [Planned measures](#planned-measures)
* [Implemented adjustments](#implemented-adjustments)

## Metadata
* **Date:** 2026-03-29
* **Location:** Underground garage
* **Focus:** Check screw connections and other errors
* **Status:** 

## Goal of the test drive
Do the screw connections hold? Are there new errors?

## Test course and result
No findings

## Error pattern and problems encountered
No special findings.

## Planned measures
No special findings.

## Implemented adjustments
No special findings.

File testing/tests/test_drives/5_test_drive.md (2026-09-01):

# Test log: 5. Test drive

## Table of contents
* [Metadata](#metadata)
* [Goal of the test drive](#goal-of-the-test-drive)
* [Test course and result](#test-course-and-result)
* [Error pattern and problems encountered](#error-pattern-and-problems-encountered)
* [Planned measures](#planned-measures)
* [Implemented adjustments](#implemented-adjustments)

## Metadata
* **Date:** 2026-04-01
* **Location:** Street
* **Focus:** Structural integrity, gearbox & speed increase
* **Status:** Partial 

## Goal of the test drive
Checking the general durability of the vehicle under load. Specifically, it should be tested whether all connections remain tight and the gearbox withstands the forces. In addition, the goal was to gradually increase the top speed and approach the 100 km/h mark.

## Test course and result
The car has proven to be highly robust. All connections and the gearbox held up without any problems and the vehicle also survived minor crashes without structural damage. However, the targeted speed increase to 100 km/h could not be realized.

## Error pattern and problems encountered
The driving behavior at the front end (front axle/front end) turned out to be incredibly spongy and unstable. This lack of precision and stability in the steering makes the vehicle uncontrollable as the speed increases, so that safely reaching 100 km/h is currently impossible.

## Planned measures
In order to get the spongy driving behavior at the front end under control and establish the necessary stability for high speeds, the following parameters must be analyzed and adjusted:

* **Differential oil:** Check viscosity in the front diff and adjust if necessary (lock/unlock) to stabilize straight-line stability.
* **Chassis geometry:** Exactly measure the setup of toe, camber and caster on the front axle and adjust for high-speed stability.
* **Suspension & damping:** Check spring rates and damper oil viscosity to prevent the front from rocking or buckling.
* **Steering components:** Check the steering servo, the servo saver and the entire steering linkage for play or insufficient actuating force.
* **Weight distribution in the vehicle:** A heavier motor (3660 instead of 3650) and a heavier battery (3S instead of 2S) are used. This could possibly have led to a problematic shift in the center of gravity.

**Conclusion for the next rollout:**
The mechanical base and the drivetrain are now pleasantly robust and "crash-resistant". Before further high-speed tests can be carried out, the absolute focus is on the chassis setup and steering precision of the front axle.

## Implemented adjustments
No special findings.

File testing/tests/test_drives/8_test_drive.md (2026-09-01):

# Test log: 8. Test drive

## Table of contents
* [Metadata](#metadata)
* [Goal of the test drive](#goal-of-the-test-drive)
* [Test course and result](#test-course-and-result)
* [Error pattern and problems encountered](#error-pattern-and-problems-encountered)
* [Planned measures](#planned-measures)
* [Implemented adjustments](#implemented-adjustments)

## Metadata
* **Date:** 2026-04-09
* **Location:** Underground garage
* **Focus:** Front end stability
* **Status:** Partial / expandable

## Goal of the test drive
Checking the driving behavior at the front end of the Carten T410R under two specific setup variants: 
a) servo saver sprung as hard as possible.
b) servo saver sprung as hard as possible in combination with 141g additional weight on the front bumper.

## Test course and result
The calmest driving behavior at the front end could be achieved with variant b (hard servo saver + 141g additional weight). A noticeable difference and an improvement compared to variant a was observed. However, the vehicle is still not 100% calm in the front area.

## Error pattern and problems encountered
During the test drive, no accidents or mechanical defects occurred. The remaining problem is limited to the residual restlessness at the front end, which has not yet been completely eliminated.

## Planned measures
The findings from variant b form the basis for the next steps:

* **High-speed attempt:** A high-speed test run can be undertaken, provided the throttle curve is dosed very carefully and sensitively.
* **Preparation spool (plan B):** If the planned high-speed attempt fails due to the front end restlessness, which has not yet been completely eliminated, the next measure must be to install a spool on the front axle.

**Conclusion for the next rollout:**
The combination of a hard servo saver and additional weight shows the right effect, but does not yet bring perfect smoothness. A cautious high-speed test is justifiable with the current setup. The option of installing a spool on the front axle remains as a technical backup for the next setup, in case the stability is again insufficient with increasing speed.

## Implemented adjustments
No special findings.

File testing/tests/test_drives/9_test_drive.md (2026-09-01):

# Test log: 9. Test drive

## Table of contents
* [Metadata](#metadata)
* [Goal of the test drive](#goal-of-the-test-drive)
* [Test course and result](#test-course-and-result)
* [Error pattern and problems encountered](#error-pattern-and-problems-encountered)
* [Planned measures](#planned-measures)
* [Implemented adjustments](#implemented-adjustments)

## Metadata
* **Date:** 2026-04-16
* **Location:** Outside on the street
* **Focus:** Maximum speed increase (speedrun)
* **Status:** Partial / aborted due to accident

## Goal of the test drive
Increase of speed and checking the driving behavior at high speed. The main goal was to push the speed of the vehicle as much as possible.

## Test course and result
A top speed of 71 km/h was measured. Without the involuntary abort, an estimated 80 km/h would have been reached. It was clearly shown that the target mark of 100 km/h is realistic and feasible on a correspondingly large and clean asphalt surface.

## Error pattern and problems encountered
* **Collision:** During the speedrun, a driving error or loss of control occurred, during which the vehicle crashed into the driver's foot. 
* **Driving behavior:** The front end still feels a bit spongy and does not yet offer optimal directional stability at these high speeds.
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

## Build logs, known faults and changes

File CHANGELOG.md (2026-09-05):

# Changelog

## [1.1.1](https://github.com/kleinnconrad/small-scale-rc-speedrun/compare/v1.1.0...v1.1.1) (2026-09-05)

### Bug Fixes

* add ride heigth to the setup_sheet and fix repo structure ([ec82257](https://github.com/kleinnconrad/small-scale-rc-speedrun/commit/ec82257cc457d3932b0909fb01e86b3d5832e2e0))

## [1.1.0](https://github.com/kleinnconrad/small-scale-rc-speedrun/compare/v1.0.1...v1.1.0) (2026-09-03)

### Features

* adding github pages setup_sheet dashboard ([9794f73](https://github.com/kleinnconrad/small-scale-rc-speedrun/commit/9794f73e0ec0930f5f7f317a28bf6329256cfaa6))

## [1.0.1](https://github.com/kleinnconrad/small-scale-rc-speedrun/compare/v1.0.0...v1.0.1) (2026-09-02)

### Bug Fixes

* minor corrections of the specs ([c406340](https://github.com/kleinnconrad/small-scale-rc-speedrun/commit/c406340bf08ea09a567a6e4af21a4bddef42dcd9))

## 1.0.0 (2026-09-01)

initial version

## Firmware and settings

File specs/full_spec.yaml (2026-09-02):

Body:
  meta:
    brand: ZooRacing
    model: Hellcat
    vehicle_class: 1:10 On-Road Touring Car
    width_mm: 190
    wheelbase_mm: 257
    material: Polycarbonate (Lexan)
    material_thickness_mm: 0.7
    shopping_item:
      add_to_list: true
      item_name: ZooRacing Hellcat 190mm Touring Car Body (0.7mm Regular)
      category: Body & Aerodynamics
      reference_link: Search at RC-KleinKram or Tonisport for 'ZooRacing Hellcat 0.7mm'
      estimated_price_eur: 32.9
  properties:
    aerodynamic_features:
      front: Low-drawn nose and gentle hood angle reduce dynamic pressure and prevent
        lift.
      roofline: Flat sloping roof guides the air laminar and undisturbed to the rear
        wing.
      rear_wing: Included high-downforce wing provides absolutely necessary rear stability
        at high speed.
Tools:
  meta:
    description: Required tools for assembling the Carten T410R.
  properties:
    tool_list:
      hex_wrenches:
        type: Hex Wrenches
        sizes: 1.5 mm, 2.0 mm, 2.5 mm
        note: Mandatory purchase! Carten uses metric M3 machine screws throughout
          the car (no self-tapping screws). A high-quality hex wrench is highly important
          here, so as not to damage the screw heads and the hard plastic thread when
          screwing in.
        brand: Neewer
        model: Titanium RC Hex Wrench Set (1.5/2.0/2.5/3.0)
      box_wrenches:
        type: RC Cross Wrench / Box Wrench
        sizes: 5.5 mm and 7.0 mm
        note: The 5.5 mm is needed permanently for all M3 nuts in the chassis. The
          7.0 mm is for the wheel nuts. The 10.0 mm mentioned in the Carten manual
          is not needed at all for this 1/10 model.
        status: Available (No purchase necessary)
      adhesives_and_chemicals:
        threadlocker:
          type: Screw Cement / Threadlocker
          note: highly important! Goes on all screws that are screwed into metal (e.g.
            motor pinion). Often incorrectly labeled as 'GLUE' in the Carten manual.
            Never use for plastic!
          brand: Loctite
          model: 243 Medium Strength (Blue)
      tapes:
        glass_tape:
          type: Glass Tape
          note: Mandatory for the T410R! The car has no classic plastic battery holders.
            According to the manual, the tape is pulled through the slots in the carbon
            chassis to strap the LiPo battery down tightly.
          brand: Arrowmax
          model: Fibre Tape / Battery Tape
Cartent410R:
  meta:
    brand: Carten
    model: T410R Touring Car Kit
    part_number: NHA413
  properties:
    carten_t410r:
      general:
        vehicle_type: 1:10 Electric Touring Car (EP Touring Car)
        delivery_condition: Kit - unassembled
        deployment_area: On-Road / Asphalt / Carpet
      dimensions:
        track_width_mm: 190
        wheelbase_mm: 258
      chassis_and_structure:
        bottom_plate: 2.25 mm Eco-Carbon (carbon fiber reinforced composite material)
        upper_deck: 2.0 mm Eco-Carbon
        shock_towers: 3.0 mm Eco-Carbon (front & rear, various mounting points)
        motor_mount: CNC-machined aluminum
        servo_mount: Floating Servo Mount (Aluminum)
        battery_mount: Prepared for 2S Standard LiPo (Stickpack) or Shorty LiPo
        body_mounts: Adjustable plastic posts
      drivetrain:
        drive_type: 4WD four-wheel drive, central shaft drive
        center_driveshaft: Aluminum (red anodized)
        differentials: Sealed bevel differentials (front & rear)
        differential_gears: Metal gears
        driveshafts: Steel CVD (Constant Velocity Drives) on front and rear axle
        spur_gear_mount: Aluminum
        wheel_hubs: 12 mm hex, aluminum
        internal_ratio: 1:2.47 to 1:2.53
        ball_bearings: Fully ball-beared (with rubber seals)
      suspension_and_springs:
        shock_absorbers: Aluminum oil shock absorbers (with threaded coilover)
        suspension_arm_mounts: Aluminum (Toe Blocks)
        sway_bars: Front and rear included
        geometry_adjustment: Continuously adjustable via R/L threaded rods (Turnbuckles)
        adjustable_parameters:
        - Camber
        - Toe
        - Caster
        - Droop
        - Ride Height
        - Ackermann
      steering:
        steering_system: Ball-bearing Dual-Bellcrank-System (Double arm)
        steering_knuckles_c_hubs: Composite plastic
Spur Gear:
  meta:
    type: CARTEN NBA360 Steel Spur Gear (48 DP, 68T)
    mechanical_load_capacity: '> 100 km/h (designed for 3S / 120A Brushless Systems)'
  properties:
    material_and_construction:
      gear_body: Steel - CNC machined
      mounting_interface: Standard 1:10 Touring car 4-hole mount
      mating_pinion: Hardened steel (mandatory)
    mandatory_modifications:
      pinion_securing:
        issue: Slipping of the motor pinion (cause of gearbox damage)
        description: In order to prevent the main gear from slipping and being destroyed
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

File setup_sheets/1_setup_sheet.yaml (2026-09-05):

meta:
  date: "2026-09-01T14:10:10+02:00"
  description: "Carten T410R speedrun setup"
  version: 1
  top_speed_kmh: null
properties:
  suspension_and_geometry:
    front_toe_deg: 0
    rear_toe_deg: 2.5
    front_camber_deg: 0
    rear_camber_deg: 0
    ride_height_front_mm: 13
    ride_height_rear_mm: 15
    spring_rate_stiffness: "hard"
    shock_oil_wt: 1000
    spring_preload_mm:
      front_left: 5
      front_right: 5
      rear_left: 5
      rear_right: 5
    droop_screws: null
    sway_bars: null
    servo_saver: null
    tire_type: "belted treaded rubber"
    tire_width_rear_mm: 24
    tire_width_front_mm: 24
  drivetrain:
    front_diff: "spool"
    rear_diff: "open"
    pinion_gear_t: 43
    spur_gear_t: 68
    internal_gear_ratio: 2.47
    final_drive_ratio: 3.91
  electronics_and_control:
    lipo_cells: 3
    lipo_capacity_mah: 5000
    max_discharge_c: 50
    max_current_a: 250
    motor_type: 3660
    motor_kv: 3700
    esc_a: 120
    esc_punch_level: 1
    bec_voltage_v: 6.0
    steering_torque_nm: 0.69
    steering_type: "digital"
    dual_rate: 40
    throttle_curve: -40
    steering_curve: -30
    steering_trim_right: 5
    steering_base_trim_right: 15
    steering_trim_left: 0
    steering_base_trim_left: 0
    gyro_gain: 40
    

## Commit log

2026-02-24 chore(docs): auto-update full_spec.yaml [skip ci]
    [full_spec.yaml]
2026-02-26 feat: add architektur
    [adr_lenkservo.yaml, adr_motorkuehlung.yaml]
2026-02-26 chore(docs): auto-update full spec and shopping list [skip ci]
    [full_spec.yaml]
2026-02-26 chore(docs): auto-update specs, docs and shopping list [skip ci]
    [full_spec.yaml]
2026-03-18 Add readme for Hobbywing QuicRun 120A ESC
    Added detailed calibration and parameterization instructions for the Hobbywing QuicRun 120A ESC, including throttle range calibration and punch setting via LED programming card.
2026-03-18 Update readme for Lasertachometer test report
2026-03-18 Revise maiden flight report with damage and actions
    Updated the damage report and corrective actions based on the maiden flight analysis, including changes to gear materials and calibration issues.
2026-03-18 Clarify punch level issue in smoke test readme
    Removed the phrase 'und unkontrolliert' to clarify the issue with the punch level during the smoke test.
2026-03-19 Document motor polarity issue and corrective actions
    Added a section about incorrect motor polarity affecting performance during the test drive.
2026-03-19 Add section on motor polarity in readme
2026-03-19 Add ESC programming options to readme
    Added programming options for ESC including running mode, cutoff voltage, punch, drag brake force, max brake force, max reverse force, neutral range, timing, LiPo cells, and BEC voltage.
2026-03-19 Add image to readme for ESC programming card
2026-03-19 Fix assembly instructions for servo horn
    Corrects the assembly instructions for the servo horn, specifying that the ball joint should be attached to the back instead of the front.
2026-03-19 Add images of Carson Reflex wheel and receiver to README
2026-03-19 Update readme with image and assembly correction
    Added an image and corrected assembly instructions for the servohorn.
2026-03-19 Add chassis_optionen.md file
2026-03-22 Add sensor and telemetry section to readme
2026-04-19 Update available track length in speedrun report
    Updated the available track length from approximately 150 meters to 130 meters.
2026-04-19 Update Einschätzung und Maßnahmen im Speedrun-Test
    Ergänzt Einschätzung und empfohlene Maßnahmen für das vordere Differentialgehäuse.
2026-04-19 Update speedrun session report by removing recommendations
    Removed recommended measures for the front differential housing issue.
2026-04-27 feat: add fan mount stl
    [fan_mount.stl]
2026-05-01 Revise readme with 3D print parts for Carten T410R
    Updated the readme to include detailed descriptions of 3D print parts for the Carten T410R, including fan mount, LiPo battery dummy, and maintenance stand.
2026-05-01 Update readme title for 3D printing parts
    Removed specific reference to 'Carten T410R' from the title.
2026-06-08 chore: unify yaml structures
    [adr_lenkservo.yaml, adr_motorkuehlung.yaml, spec_servo.yaml]
2026-07-07 docs: initialize project documentation, architecture design records, technical specifications, and test data logs.
    [adr_lenkservo.yaml, adr_motorkuehlung.yaml, spec_servo.yaml]
2026-07-21 docs: add test report for second speedrun session documenting chassis configuration fixes
2026-08-09 Specify motor model for replacement in test report
    Added specific motor model for replacement in measures.
2026-08-20 chore: update all steering related adr and specs and shopping list
    [adr_lenkservo.yaml, spec_servo.yaml]
2026-08-20 fix: update adr dates and bom
    [adr_lenkservo.yaml]
2026-08-20 chore: update bom with details
2026-08-20 chore: updated BOM
2026-08-21 chore(docs): auto-update specs and docs [skip ci]
    [full_spec.yaml]
2026-08-21 feat: translate repo from german to english
    [adr_motor_cooling.yaml, adr_steering_servo.yaml, fan_mount.stl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]
2026-08-21 fix: translate spec yamls to english
    [full_spec.yaml, spec_cartent410r.yaml]
2026-08-22 feat: add steering insights to the learnings section and contributed also to the error_log
2026-08-25 Update motorization and steering mechanics sections
2026-08-25 Update motorization and drivetrain sections in readme
2026-08-30 feat: add gyro adr and specs. Update costs
2026-08-30 fix: update units usage in set up sheet
    [2026-08-30_setup.yaml]
2026-08-30 Add ride height and spring rate to setup YAML
2026-08-30 Add BEC voltage configuration to setup YAML
2026-08-30 Update battery configuration in setup YAML
2026-09-01 Adjust steering trim and base trim values
2026-09-01 Update gyro_gain to null in setup sheet
    Changed gyro_gain value from 0 to null in setup sheet.
2026-09-01 Add steering trim settings to setup sheet
2026-09-01 fix: upper case usage
2026-09-01 Remove images of drivetrain damage from test drive report
    Removed images and their captions related to drivetrain damage from the test drive report.
2026-09-01 Revise maintenance steps for wheel suspension
    Updated the maintenance steps for wheel suspension, including securing ball joints and safety checks.
2026-09-01 Update readme by removing unnecessary sections
    Removed table of contents and test track exploration sections from the readme.
2026-09-02 chore: moved all specs to new specs dir and adjusted merge_specs action
    [fan_mount.stl, lipo_mock.stl, spec_servo.yaml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]
2026-09-02 chore: rename adr's
    [adr_006_steering_servo.yaml, adr_007_motor_cooling.yaml]
2026-09-02 fix: minor corrections of the specs
    [spec_battery.yaml, spec_charger.yaml]
